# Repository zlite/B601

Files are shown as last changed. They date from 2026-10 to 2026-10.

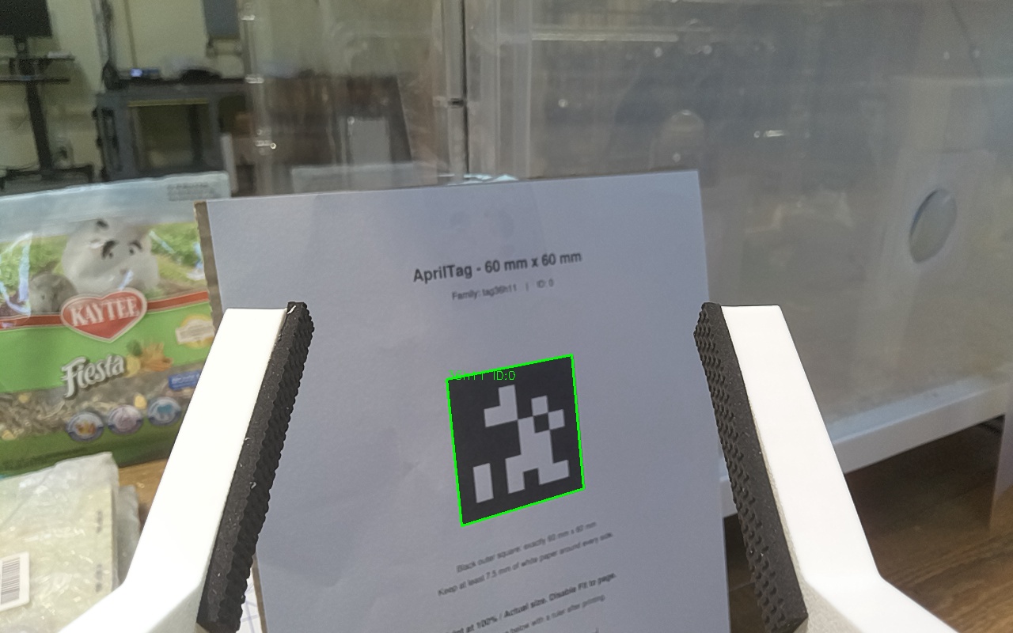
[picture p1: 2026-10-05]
calibration/handeye_20261001T234501896017Z_007.jpg

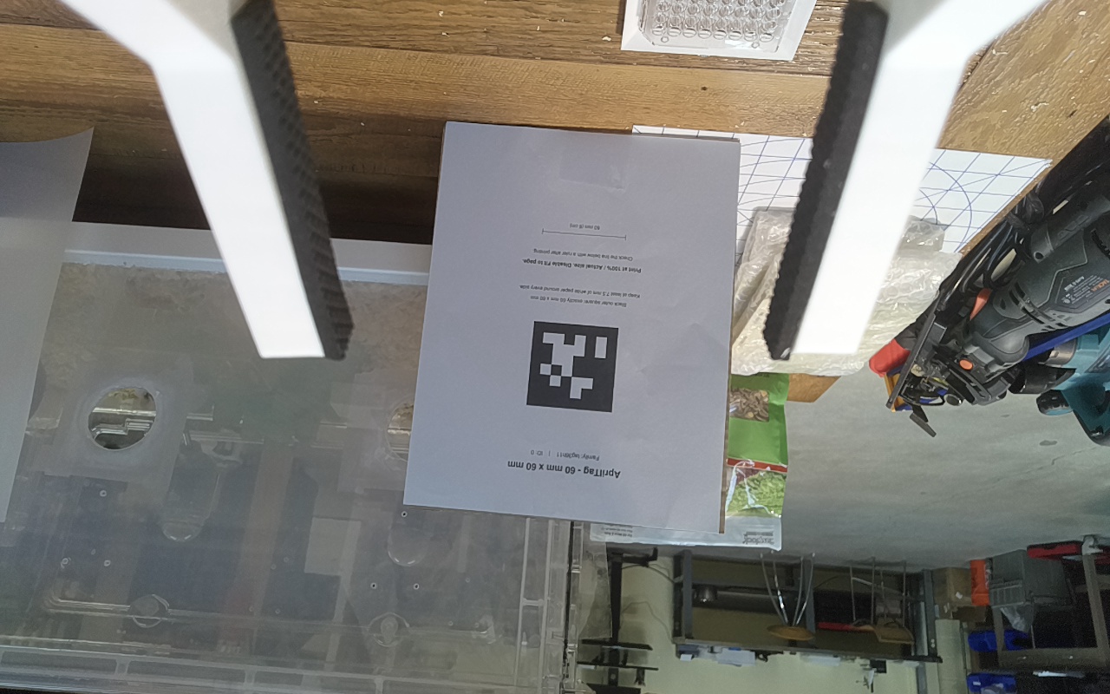
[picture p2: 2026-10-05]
calibration/handeye_20261001T234501896017Z_014_raw.jpg

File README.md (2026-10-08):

# B601-DM + OAK-1 hello-world

A gentle wrist wave while reading RGB images from the wrist-mounted Luxonis OAK-1.
Uses Seeed's motorbridge driver and Luxonis DepthAI v3. No recalibration or zero-position writes.

## Current printer teaching and rail demo (October 7, 2026)

October 8 camera-guided targeting commissioning supersedes the replay below.
The fixed demo is disabled. `printer_plate_vision.py` independently acquires
the complete 12×8 well lattice in the OAK stereo pair, validates 9 mm spacing,
rigid fit and reprojection, and rejects incomplete/ambiguous observations.
It reports a symmetric plate pose, **not A1 well identity**. A separate process
keeps grid detection off the live camera and motor threads. No historical
well-grid bootstrap or saved bed-to-plate offset is used.

`printer_target_plan.py` requires stationary joint readback bracketing the
exposure, the bed tag in that same stereo pair, a fresh stopped rail, and
current arm calibration. It composes bed-attached obstacles with the observed
bed pose, plate obstacles with the independently observed plate, and leaves
printer frame/gantry/syringe obstacles fixed. It solves a fresh local side
approach stopping 65 mm above the plate; it does not translate the old replay.
The planner inflates external obstacles for registered uncertainty and joint
tracking bounds. Its output is a **preview**, not an executable authorization:
full self-collision checks, validated geometry and a physical rehearsal remain
necessary. It cannot automatically move from rest to an unseen target.

The web panel shows localization failures and offers raw stereo capture and
preview without any motor commands. Preview requires three independent stable
observations and is invalidated by target movement, stale data, a camera restart
or rail movement. `config/printer_target_scene.json` deliberately leaves the
unmeasured scene/tool registration incomplete. Automatic target-relative
execution and plate pickup are **not commissioned or implemented in the demo
executor**. Live acquisition at a clear observation pose, scene/tool calibration,
an independently checked acquisition corridor and execution integration are the
remaining work; software tests are not physical validation.

Read-only tools:

```bash
.venv/bin/python scripts/printer_target_client.py status
.venv/bin/python scripts/printer_target_client.py capture
.venv/bin/python scripts/printer_target_client.py preview
.venv/bin/python scripts/analyze_printer_grid.py <target_captures/stage_01>
.venv/bin/python scripts/printer_stereo_viewer.py <teaching-session/target_captures>
.venv/bin/python scripts/dashboard_read.py --brief --axes
```

The standalone stereo viewer serves upright **snapshots**, with visible image
age, at `http://127.0.0.1:8766`. Its only action requests a raw image capture
from the existing camera owner; it has no arm or rail controls and needs no
controller restart. Use it to check both measuring-camera views: the RGB
preview can look clear while a finger obscures the tag or plate in one eye.

October 8 contact incident supersedes the close-approach validation below:
the operator confirmed that the arm knocked the plate out. Recorded wrist
frames show the plate being dragged and tilted during the return of cycle 6;
cycle 7 later paused on roll settling. A completed motor trajectory report is
not evidence of collision-free operation. The old plate-level route is retired.
The replacement `standoff_recovery_20261008T2024` retains only the first two
approach groups, omitting the final three descent groups and `plate_view`.
Its tool bottom is approximately 82 mm higher in the model; this is a relative
pose difference, not a calibrated measurement of clearance from the scene.
All 1,150 stock/tool/camera geometry samples passed, with camera review of
external structures and 16 focused tests. One bounded rail/standoff/return trial
completed in 104.16 s of arm motion, with no visible plate displacement in
reviewed camera views and motors disabled at rest. Repeating standoff demo
then restarted. This does not validate the retired plate-level route.
The original plate-contact cause and scene-relative pickup targeting still
need investigation; this shortened demo does not attempt pickup.
Evidence: `outputs/printer_replay/contact_incident_20261008/diagnosis.json`.

October 8 process-exit recovery: the 17:38 UTC controller recorded 42 completed
cycles before its recording ended abruptly at 19:27:49 UTC, with no final report
for the interrupted return. All six motors subsequently reported communication
watchdog faults. The process termination cause is unresolved. After operator
confirmation of supported rest, faults were cleared without enabling motors.
The final folded rest (joint 3 about 99.50 degrees) passes the unchanged rail
parking interlock; a fresh entry and reverse passed stock-arm, tool and camera
mesh checks in `outputs/printer_replay/folded_recovery_rest_20261008T2000`.
The 20:01 UTC controller also saves console output to
`outputs/printer_teach/controller_20261008T2000.log` for diagnosis.

October 8 roll-load correction (two complete live trials passed): increasing endpoint
wait time alone did not resolve a persistent .95-degree roll offset. Roll's MIT
controller used Kp=18, Kd=2 and no feedforward; observed stationary torque was
about .32 Nm. Demo-only command gains are now Kp=30, Kd=2.6, set only while all
motors are disabled. The damping increase approximately follows the square root
of the stiffness ratio. Teaching restores Kp=18, Kd=2 after a disabled demo end.
No motor mode, EEPROM, zero, commanded path, tracking cutoff or endpoint
tolerance changes. Both trials returned to rest and disabled normally, without
pauses or faults; the repeating run then began its next rail cycle. The loaded
endpoint roll errors were .543 and .544 degrees (unchanged .75-degree tolerance),
and maximum tracking errors were 1.019 and 1.022 degrees (unchanged 1.5-degree
fault limit). Arm cycles took 125.15 and 125.08 seconds. Peak observed motor
temperature was 36 C. These are two-cycle results, not long-duration validation.
Summaries: `outputs/printer_replay/ui_demo/20261008T171425593243Z/summary.json`
and `outputs/printer_replay/ui_demo/20261008T171938199644Z/summary.json`.
The main suite ran 370 cases with four optional CAD skips.

October 8 endpoint follow-up: the first updated cycle completed, but cycle 2
paused at `settling_timeout`. Roll was still about .77 degrees from its target
at the four-second deadline, and subsequently converged inside the unchanged
.75-degree endpoint tolerance. Endpoint holding now permits up to eight seconds,
exits as soon as all original tolerances pass, and reports the limiting joint
and measured error if it times out. Camera/attendance readiness is checked
during settling as well. Recorded-convergence and nonconvergence regressions
passed. A subsequent eight-second live trial still paused with .955-degree
roll error and was returned along its checked route with motors disabled.

October 8 roll-pacing correction: the next sequential-reader run stalled near
the plate while joint 6 retained almost exactly one degree of command error.
The trajectory clock and command cap both stopped advancing at that error.
Replay now permits 1.25 degrees of command error on roll only, while the other
five axes retain their one-degree pacing margin. The independent measured
tracking stop remains 1.5 degrees; gains, path geometry, joint limits and speed
limits are unchanged. Near the pacing cap, less than .02 degrees of commanded
progress over five seconds causes an explicit joint-specific held pause.
Tests exercise the recorded starting error with simulated breakaway in both
directions, a nonfollowing joint, and the independent tracking stop. The main
suite passed 364 tests (four CAD skips); those four passed in `.venv-cad`.
Physical recovery and the combined gain/pacing update passed the trials above.

October 8 communication recovery supersedes the fast-reader results below:
the concurrent reader is now experimental and off by default. The teaching
controller uses the original sequential reader while retaining the smoothed
route and existing speed/acceleration bounds. An observed long-hold deadline
failure is recorded in the local trial `20261008T160050434745Z`; all six motors
subsequently reported LOST_COMM. Powered-fault report writing and CAD-worker
shutdown now wait until the motor owner's cleanup attempt and handle closure
finish. The original control fault is retained alongside any cleanup error,
and power state becomes unknown until fresh verification instead of retaining
a stale `powered: true`. Tests inject the deadline and a second cleanup failure
and verify that no report writing occurs before motor cleanup.
The operator confirmed supported rest before the six communication faults were
cleared and disabled status was verified. The configured entry was checked again
from that actual rest in `outputs/printer_replay/recovered_rest_20261008/`.
The ~129 s sequential-reader cycle is the previous measured reference; the
combined live trials above use the sequential reader.

October 8 power-up recovery: the old worker retained a position-read timeout
fault after motor power returned. Position transactions now get one bounded
fresh retry, like status reads; the 120 ms batch deadline and fault guards stay
unchanged. A disabled starting pose outside the teaching envelope keeps live
readback running and blocks teaching instead of killing the connection.
The operator confirmed normal supported rest, differing from the prior start by
up to 2.71 degrees. A new entry and its reverse passed the existing stock-arm,
gripper and camera mesh checks, preserving the unchanged route tail, in
`outputs/printer_replay/powerup_rest_20261008/`. The Demo config uses that entry;
joint limits and live start tolerances were not widened. Demo readiness was
verified with motors disabled; a motion trial from this new entry is pending.
72 focused tests passed. Refresh the browser after a controller restart to
obtain its new action token before using Demo.

Run `.venv/bin/python printer_teach.py` and open `http://127.0.0.1:8765`.
The controller starts with the arm disabled. The page supports relative leader
teaching, held-arrow rail jogging, and the confirmed same-scene Demo: rail
300 mm left and back, then open-jaw plate approach and return, repeating until
Stop. Pause holds immediately; Stop completes the current cycle at rest.
The demo does not grasp or lift the plate. Fresh resting-pose, scene and rail-sweep
confirmations are required each start. Changed bed positions require new targeting.

Historical fast-reader trial (superseded by the sequential-reader correction
above): the bounded trial returned to rest with motors disabled and rail X=0.
Three smoothed motion sections replace seven
stopped chunks, with maximum checked joint-path deviation 0.071 degrees.
Fresh concurrent motor reads reduced the measured full arm cycle from 129.24 s
to **114.14 s** (11.7% less time). Median control-loop interval fell from
50.86 ms to 11.68 ms; the new 95th percentile was 16.60 ms and maximum 88.57 ms.
Peak tracking error was 0.981 degrees against the unchanged 1.5-degree fault
limit. Motor gains, speed limits and acceleration limits were unchanged in this
comparison. Rail-return-to-arm-motion measured 2.07 s, including the fresh
entry geometry check. This is one measured cycle, not a long-duration reliability
claim. Its summary is versioned at
`outputs/printer_replay/ui_demo/20261008T011256235081Z/summary.json`.

The optional pinned native reader, build command, freshness behavior and
read-only benchmark are documented in [native/motorbridge/README.md](native/motorbridge/README.md).
Without that build, the controller uses the original sequential reader.
The exact reviewed route and collision inputs/results under
`outputs/printer_replay/smooth_demo_v1/` are explicitly versioned so the trajectory
is preserved. Bulk session logs, camera recordings and compiled binaries remain
local. Geometry files retain their source hashes, including workstation paths:
a different checkout location or changed geometry needs fresh evidence rather
than edited hashes. The existing pinned vendor geometry and isolated CAD
environment are still required for the demo entry checker.

For an attended single-cycle test, use
`.venv/bin/python scripts/printer_demo_client.py start --once` after verifying
the same scene and clear movement area. It maintains the attendance heartbeat
and requests stop at the end of the first cycle. No client automatically resumes
a paused trial. The sections below preserve chronological development history;
older pending-state descriptions are superseded by this current status and
`config/printer_resume_state.json`.

## Relocated workspace and Arducam overview (October 6, 2026)

The operator confirmed that only the arm location and tripod camera changed;
the wrist camera, fingers and their mounts stayed unchanged. Existing plate,
holder and table references remain historical. The relocation marker remains
active, and both plate-hover and the standalone old survey route check it before
opening hardware. No new motion path has been validated.

The tripod is now an Arducam Global Shutter 2.3MP with a replacement fisheye lens,
serial `Arducam_20260506_0001`. `config/cameras.json` selects its stable V4L2 path,
MJPEG at **1920×1080, 30 fps**. USB 3 is required: the initial USB 2 hub connection
advertised only 640×480 at 10 fps. Moving it to a 5 Gbps connection exposed the
full modes. The configured USB 3 path/serial deliberately fails closed on a
different device or USB 2 fallback; the backend does not silently resize frames.
Manufacturer mode table:
https://www.arducam.com/arducam-2-3mp-color-global-shutter-usb3-uvc-camera-module-with-onboard-isp-for-robotics-and-machine-vision.html

`uvc_camera.py` supplies an overview image with its native aspect ratio and
advancing driver timestamps. It provides no camera matrix, distortion parameters
or metric pose; OAK-1 calibration must never be applied to these fisheye pixels.
V4L2 driver-buffer age is not independently measured exposure-to-display latency.
The timestamp comes from OpenCV's V4L2 `CAP_PROP_POS_MSEC` implementation:
https://github.com/opencv/opencv/blob/4.12.0/modules/videoio/src/cap_v4l.cpp

Start the read-only camera/arm dashboard with `.venv/bin/python pairing_dashboard.py`
and open `http://127.0.0.1:8765`. It has no motor activation/movement endpoint.
Stop it before any other device client. For a new stationary image record, run
`.venv/bin/python scripts/workspace_capture.py`; this camera-only tool creates a
unique folder under `outputs/workspace_revalidation` and never clears the motion
block. Fresh tripod frames are retained at native 1080p; wrist images retain their
existing calibrated sensor coordinates and separate upright previews.

The first successful dual-camera record is
`outputs/workspace_revalidation/20261006T183131149101Z/report.json`: 55 sampled
tripod frames and 20 wrist frames, median driver/SDK frame ages 16.3 ms and
101.0 ms respectively. Neither reference tag decoded at the resting pose.
`outputs/contact_camera/20261006T182403188657Z/report.json` separately preserves
12 stationary wrist RGB/stereo triplets; none established a tag pose.
Read-only inspection found all six arm drives and the gripper disabled, with
gripper position −1.15238 rad. The existing Python environment's broken symlink
into `/tmp` was repaired to point to its already installed local interpreter.

The operator subsequently confirmed that the target or task has changed. The
new object, interaction and destination are pending; do not assume the old plate
pickup task or reacquire its geometry as the new task. Define the new task before
planning its workspace measurements or empty-jaw rehearsal. The new view includes
nearby gantry structure; old clearances and trajectories are not evidence for this
workspace. Fifteen focused camera, pairing and relocation-gate tests passed.

The new target was then identified as a 96-well plate on a 3D printer bed, with
AprilTag **36h11 ID 18** in front. `config/printer_bed_target.json` records the new
identity separately from the historical tag-0/contact configuration. The tag's
physical black-square size and requested plate operation are awaiting confirmation.
Current wrist RGB and both mono cameras decoded ID 18 in all 12 triplets saved in
`outputs/contact_camera/20261006T183713670011Z/report.json`. Independent stereo
triangulation, without a tag-size assumption, puts its center approximately
200 mm from camera B and its four side lengths at 17.9–18.4 mm. This is an
observation, not a substitute for physical size confirmation or a bed/plate pose.
The center's stationary coordinate standard deviations were 0.023, 0.056 and
0.110 mm; maximum stereo reprojection error was 0.711 px. Details are in that
folder's `tag18_stereo_observation.json`.

Fresh native-resolution RGB/overview evidence is in
`outputs/workspace_revalidation/20261006T183755006277Z/report.json`. The dashboard
now annotates visible tags even when they are not the old metric reference.
Discovery with `contact_camera_probe_v2.py --all-tags` no longer assigns the old
60 mm size to an unknown tag. A metric capture requires an explicit paired
`--tag-id` and `--tag-size` in metres (or the original default tag definition).
Twelve focused probe, stereo geometry and pairing tests passed. Arm and gripper
readback remained disabled; no motion was commanded and the relocation block
remains in place. The printer's bed and gantry introduce geometry absent from
the old tabletop routes.

The operator confirmed ID 18's black square is **18 mm** and requested a lift
and replacement at the same position, with a collision-aware side approach.
The 12 stereo-only tag fits pass their size, reprojection and rigid-square
checks, but RGB/stereo comparison fails: the 640×360 RGB tag pose differs by
about 21 mm. The later 1280×800 RGB observation also differs from stereo in
range. Do not treat the combined metric check as passed or use this discrepancy
as permission to relax thresholds. Lower-exposure stereo evidence is saved in
`outputs/contact_camera/20261006T184603745832Z`.

`printer_approach.py` is a new **offline-only** plate-frame IK candidate generator.
It does not open hardware and has no execute option. It generates retreat/rise,
alignment outside the fixture, side-entry and a 40 mm noncontact standoff,
plus the reverse sequence. Parallel-jaw orientation symmetry avoids a spurious
180-degree wrist flip when the newly seeded grid axes differ from the old grid.
The current candidate has 248 waypoints, maximum adjacent joint step 0.759°,
and large overall changes (approximately 37° base and 41° shoulder), so fingertip
clearance alone is insufficient. Candidate and manual 96-well image registration
are under `outputs/workspace_revalidation/20261006T183755006277Z/`.

The seven missing stock-arm collision meshes were retrieved from the same pinned
Seeed commit as the URDF. Their hashes/bounding boxes are recorded in the candidate.
A 1,344-sample stock-link box check clears a **provisional plate volume only**
with 15 mm obstacle inflation; this is not complete scene or tool validation.
Printer bed, fixture, adjacent container, gantry and installed tool/cable volumes
still require registration/verification. The corrected operator-supplied deck is
retained at `cad/printer_bed/LH_deck_four_bolt.stl`, with provenance, hash, dimensions
and correspondence evidence in `LH_deck_four_bolt.inspection.json` beside it.
Its plate recess, adjacent square support and mounting pattern match the scene.
The mesh bounds are 202.58 × 186 × 14.2 native units; millimetres are provisionally
supported by a 170 mm CAD mounting-hole spacing versus approximately 171.95 mm
between manually marked stereo bolt-head centres. The plate opening at CAD
z=6.2 mm is 128.36 × 86.08 mm; the raised rim reaches z=14.2 mm.

A three-feature stereo registration candidate has maximum stereo reprojection
error 0.17 px and maximum rigid-fit residual 1.60 mm. These residuals do not
validate the registration: bolt-head height is assumed, one oblong-slot centre
is manually approximated, and elevated rim landmarks still need independent
verification. The tall container and printer gantry are not included in the STL.
Six-view inspection of the earlier, superseded bracket export is preserved as
historical evidence; it is not the configured deck. Corrected deck views and a
provisional stock-arm/deck bounding-box diagnostic are in `outputs/holder_cad/`.
`config/printer_bed_target.json`
records these unresolved items and stays `motion_ready: false`; the old relocation
marker remains. Twenty-two focused tests pass. No motors have been enabled and
no physical rehearsal, grasp, lift or replacement has been attempted in this setup.

The operator measured the plate top **10 mm above the holder rim**, confirmed
there is no removable lid, and said the printer bed stays still during the pickup.
The bed may occupy a different Y position between attempts. Every attempt must
therefore reacquire a fresh wrist stereo reference and check plate seating; an
old saved bed position is never an executable target. Bed-attached geometry must
move with the observed bed; the fixed printer gantry must not.

The October 6 19:20 UTC capture in
`outputs/contact_camera/20261006T192021891418Z/` has 11 valid stereo tag fits.
The tag moved 52.98 mm relative to the wrist while subsequent arm readback was
essentially unchanged. All earlier printer approach candidates are consequently
historical and explicitly invalid for the current scene. The operator's 10 mm
height plus the preliminary CAD registration also disagrees with the old RGB
plate seed by 8.73 mm in centre position; the tag-to-plate transform is not yet
validated.

The offline approach solver now aligns the **measured** contact-pad direction
instead of the nominal 45-degree bend. `printer_grasp_clearance.py` adds sampled
pad-volume checks and a full-face contact-height diagnostic. The earlier
8 × 61 mm pad calculation is superseded: the operator confirmed **both installed
pads are 60 mm long, 10 mm high and 3 mm thick, flush with the printed finger
ends**. A 10 mm pad has zero full-face height tolerance in a nominal 10 mm band;
one degree of pitch adds approximately 1.05 mm to its vertical extent. A pad
projecting above the plate may permit partial-face contact, but its contact area,
grip and rim clearance still require validation. Historical pad-only trajectory
checks do not validate the new geometry or the displaced bed.

The supplied `cad/grippers/B601_clean_braced45_assembly.step` has explicit mm
units. `cad/grippers/inspect_step.py` extracts the two rigid fingers into 28
conservative section boxes; `gripper_cad.py` adds two measured pad boxes from
`cad/grippers/installed_pads.json`, replacing the STEP's 61 × 8 × 1 mm pads.
The reference plate in the STEP is excluded from the robot collision model.
At the same rigid-body opening the extra rubber reduces the gap by 4 mm relative
to the CAD pads. This is not a measurement of the current open gap.

Distal pad ends are placed at CAD X = −32.5 mm; vertical centering on the plastic
face is still a hypothesis. Stereo landmark registration is also provisional.
The candidate in `outputs/gripper_cad/installed_pad_registration_candidate.json`
brackets center/upper-seam landmark hypotheses; this is not a certified error
bound. It excludes the gripper housing, camera mounts, cables and self-collision.
The earlier nominal-pad and tool/deck reports are marked superseded. No motion
is enabled by importing CAD or passing an offline box check.

`pairing_dashboard.py --printer-target` selects a read-only stereo tracking mode.
`printer_target_tracker.py` rejects stale/lost/restarted/displaced references and
permits a base-frame tag estimate only with fresh stationary joint history. It
cannot yet localize the plate or authorize motion. The stereo mode uses a separate
DepthAI 2.32 camera subprocess because the DepthAI 3 generic three-camera pipeline
crashed during sensor startup. The normal RGB-only dashboard mode is unchanged.
Inspect the current observation with
`.venv/bin/python scripts/dashboard_read.py --brief --target`.

The small-tag retry (`detect_small`) recovered the missed detection in all 12
saved stereo pairs without relaxing the metric checks. The live 15-second check
at `outputs/printer_tracking/20261006T193318873835Z.json` observed 75/75 valid
samples, with maximum observation age 149 ms. This validates detection/freshness,
not grasp precision: the small tag's raw orientation varies enough to trigger
conservative reference invalidations even during this stationary check. The
focused geometry, tracking, capture and relocation-gate tests pass. No arm or
rail motion has been commanded. The operator confirmed the gantry/toolhead
also stays stationary during trials and supplied the finger CAD described above.

The operator also identified a later phase: the arm base rides on a stepper-driven
rail controlled by a computer-connected GRBL/Arduino board, with an X+ limit
switch. Rail homing and positioning are deferred until stationary plate pickup
is reliable. No rail commands have been sent. Controller settings, limit polarity,
homing direction, travel limits and the rail-axis/base transform must be measured
before coordinated rail/arm motion. Rail position must update all workspace
transforms and collision checks; existing references apply only to the current
stationary rail position. This deferred work is recorded in the target config.

### Continuing from the operator-selected pose, October 6

The operator repositioned the arm and relocated tag 18. Earlier base-frame
targets and paths remain invalid. `scripts/printer_stationary_capture.py` now
brackets every camera exposure with read-only arm/gripper telemetry and rejects
captures with arm/jaw movement, missing time coverage or long readback gaps.
The accepted capture is `outputs/contact_camera/20261006T205427296547Z/`.
Its joint report verifies a stationary arm and gripper at −1.15243 rad.
The camera probe records exposure timestamps on the host monotonic clock and
can fit B/C stereo independently of RGB visibility. It never commands motors.

At the new viewing angle 2000 us overexposed tag detail in the mono cameras.
1000 us, ISO 100 recovered 10/12 offline stereo fits; live tracking then gave
50/50 valid samples in `outputs/printer_tracking/20261006T205755527700Z.json`.
The dashboard uses that exposure. Small-tag orientation remains noisy, and
successful detection does not establish a validated tag-to-plate transform.

The elbow starts within its nominal model range but inside the extra 0.005 rad
planning margin. The offline solver admits this measured start only with
inward recovery: bounds tighten as the joint recovers and cannot reopen.
No nominal joint limits are widened. A 1.2 rad offline search radius finds a
continuous candidate; the former 0.8 rad local search bound was too narrow.
The return candidate ends at the raised outside-fixture pose, avoiding a return
to the near-limit starting pose. This is an offline IK change, not permission
to energize motors or evidence of calibrated motion accuracy.

The retained offline candidate is
`outputs/contact_camera/20261006T205427296547Z/side_approach_current_pose_standoff65_candidate.json`.
It ends at a 65 mm noncontact standoff above the provisional plate plane.
The more aggressive 40 mm descent intersected an oversized container hypothesis
and is not the selected candidate. Visible stereo points place the container
top near 45 mm above the provisional CAD datum; the revised diagnostic uses a
55 mm-high, 62 × 62 mm envelope, plus the existing 15 mm obstacle inflation.
That local finger/container check passes with a 9.2 mm separating-axis gap
beyond inflation. The provisional deck check also passes. Neither check covers
the entire scene: holder registration, installed tool details, self-collision,
the gantry/toolhead, surrounding structures and rail still require validation.
The plot `current_pose_trajectory_review.png` shows the substantial arm sweep.
No motion has been commanded, and the relocation marker remains set.

The stock Ender 3 assembly is retained at `cad/ender3/Ender3.STEP`, from
Creality commit `88c7758cea9d0d00a54fdb238bedb3b33425f409`. Its 311 located
components and selected structural bounds are in `inspection.json` and
`structural_reference.json`. These are unregistered reference geometry:
the bed travel and gantry height in the STEP are not the current machine's
positions, and the custom syringe drive, needle and rail are absent.
`inspect_step.py` preserves repeated instances and resolves their product names.

A small offline wrist-bend observation candidate was also checked using stock
triangle meshes. The saved folded starting pose has a modeled link2/link5
surface intersection; link2/link4 separation during that candidate is only
about 0.6 mm. This does not establish physical contact, but prevents declaring
the move clear. The camera cannot resolve that narrow gap. The operator was
asked whether there is visible physical clearance, without moving the arm.
`scripts/stock_mesh_self_check.py` provides a reproducible FCL diagnostic of
precomputed collision-mesh transforms. It excludes adjacent engineered joints,
checks all other pairs, and never authorizes motion. It checks triangle surfaces,
not solid containment, and does not cover the custom tool or external obstacles.

The full 65 mm-standoff candidate was subsequently **rejected** by the stock
self-check: 295 of 1,577 interpolated samples have less than 5 mm separation,
and 236 samples report link2/link5 surface intersection, all during the initial
`retreat_and_raise` stage. See `side_approach_stock_self_check.json` in the
accepted-capture directory. The earlier fixture clearance result does not make
this trajectory usable. A different initial unfolding motion is required.

Fresh readback at 21:26 UTC differs from the saved capture by about 1.17 degrees
at joint 1 and 0.42 degrees at joint 4. The ten-second sample was stationary,
but only 8/50 tag observations were valid (tag clipped in the wrist view).
Historical tracking success and saved paths must not be treated as current
validation. See `outputs/printer_tracking/20261006T212600370966Z.json`.

From that fresh readback, an offline alternative first reduces raw joint 3 by
2 degrees, then raw joint 4 by 8 degrees. This raises the modeled fingertips
about 61 mm. Its 101 stock-mesh samples show no surface intersections, but the
first 15 samples remain inside the 5 mm diagnostic margin while unfolding.
This is a promising observation candidate, **not a cleared movement**: physical
starting clearance, complete tool geometry and external swept clearance remain
unverified. Reports are `local_observation_mesh_input.json` and
`local_observation_stock_self_check.json` in the accepted-capture directory.

### Return to normal rest, October 6 at 21:36 UTC

The operator confirmed that the wrist housing physically touched the long beam
in the previous pose, then manually returned the arm to normal rest. The new
stationary, disabled-arm/gripper capture is
`outputs/contact_camera/20261006T213644834808Z/`. Tag 18 is outside the wrist
view (0/12 detections), which is expected at rest and is not itself a reason to
reuse an old target pose or approach.

An offline search candidate unfolds the elbow 30 degrees, turns the base about
72 degrees, then aims the wrist camera toward the historical target bearing.
`rest_search_mesh_input.json` and `rest_search_self_check.json` record 1,703
stock-mesh samples with no surface intersections. The first 16 samples retain
less than 5 mm separation as the folded arm begins opening. A coarser 171-pose
finger/pad check reports no sub-5-mm proximity to stock links 0–5. This does not
validate the camera housing, gripper motor, cables or external scene. It is
not an execution plan, and the tag must be reacquired before plate targeting.
Several wrist-steering alternatives were rejected because of modeled
self-intersection or insufficient clearance.

The operator adjusted the ArduCam twice; the rear elbow and adjacent bench
are now visible. Earlier front views are retained. This camera remains an
uncalibrated overview; no metric clearance is inferred from its fisheye pixels.

The first physical observation trial, `20261006T215822174941Z` under
`outputs/printer_observation_lift/`, lifted the elbow eight degrees at a
1 degree/s cap, then returned along the same segment. All six drives held
position; gripper and rail were untouched. Maximum elbow tracking error was
0.259 degrees, and motor shutdown was independently verified. The wrist bend
settled about 0.66 degrees after shutdown, so subsequent plans use fresh joints.
This validates one bounded lifting segment, not a plate approach or pickup.

The updated offline viewing route unfolds the elbow 20 degrees, raises the
shoulder 12 degrees, then turns and aims the camera in separate small steps.
Its settled-start evidence is in `outputs/printer_observation_route/settled_20261006/`.
The stock gripper base is included as a fixed part of link6. A conservative
camera enclosure bound and the supplied finger/pad hypotheses were checked
separately. Printer registration, mount/cable envelopes, and grasp registration
remain incomplete. `printer_observation_route.py` defaults to preview; execution
requires fresh images to be reviewed at each stopped waypoint. Missing review
or a camera freshness failure triggers retrace; motor faults use torque-off
cleanup. This observation controller does not clear the workspace pickup block.

Staged run `20261006T221343056382Z` completed seven waypoints: elbow opening
20 degrees, shoulder lift 12 degrees, and base rotation to 20 degrees. Images
were reviewed between segments. At the last stop the raised rear elbow reached
the lower overview-image boundary, so further rotation was canceled. Controlled
retrace to rest and disabled drives were verified. Maximum tracking error was
0.264 degrees. No grasp, gripper or rail command occurred, and the target tag
was not reacquired. The operator was asked to move the ArduCam farther away and
higher to cover the complete turning area. The arm settled again after power-off;
the saved route must be regenerated from fresh joints before another execution.
Evidence and images: `outputs/printer_observation_route/settled_20261006/20261006T221343056382Z/`.

The operator cannot move the ArduCam farther back or higher; its placement is now
fixed. The compact observation run at
`outputs/printer_observation_route/compact_fixed_camera/20261006T222626191083Z/`
completed 16 stops but aborted during the final wrist bend: roll drifted 0.571°
from its fixed target, beyond the 0.55° envelope. This caused torque-off cleanup,
not controlled retrace. The arm settled under gravity; a separate read-only
inspection confirmed all six drives disabled. Hold compliance is a possible
cause, not a completed diagnosis. The user manually returned to rest, then
rotated the follower to align with the newly connected leader. Old route starts
are invalid. No pickup or rail operation was performed.

`printer_teach.py` provides an attended approach demonstration panel at port
8765, starting with all motors disabled. It reuses the existing relative,
hold-to-follow controller with the existing 18°/s, 60°/s² first-three-axis profile
and 24°/s, 80°/s² wrist profile. Model/local travel limits and motor guards remain
active. Teaching captures the leader reference on the first press and preserves
it through startup, limit saturation and ordinary pauses. A resumed press requires
the leader's mapped request to match the held follower within 1°; the explicit
Re-align button accepts the current pair of poses during powered pause without
moving the follower. It never matches old absolute encoder origins. Release
pauses with motor power on. Motor
power removal requires physical support; faults may still remove torque.
The first pass stops before plate contact; gripper control remains inactive.
The printer stereo runtime and current ArduCam feed are used without moving the
overview camera. The revised panel/controller passed 76 combined rail, teaching,
axis-following, wrist-following and observation tests; the live page was visually
checked. Teaching uses 20 ms smoothing with braking at the requested target to
avoid command overshoot, and a 5 ms leader polling pause instead of 20 ms.
Other clients retain their existing mapping and trajectory policy. Motor
feedback polling, gains, speed limits and fault checks remain unchanged.

The October 7 demonstration showed additional alignment shifts at startup and
re-press (about 3.1° on joint 4), rather than within the second uninterrupted hold.
Joint 3 also repeatedly reached its folded-end model limit after startup/re-press
discarded leader movement. The latest reference policy removes those silent
changes; it does not expand joint ranges. Dynamic motor tracking lag reached
about 6° during the earlier trial and still needs a measured physical retest.
No physical gain/scale correction was inferred solely from these encoder logs.

The October 7 session `20261007T231900689788Z` isolated the reported joint-2
descent problem to the shoulder's local 60° teaching window. The leader requested
128.4° while both the command and measured follower stopped at a 60° excursion.
`teaching_profiles()` now allows the shoulder's full model-defined range by
using a 180° local window intersected with the existing calibrated URDF bounds
and endpoint margin. Shoulder speed remains 18°/s and acceleration 60°/s²;
tracking checks, other joints' ranges and hardware limits are unchanged.
55 teaching/axis/rail tests passed, including the recorded 128.4° request,
trajectory limits and saturation at the model endpoint without reference drift.
After a supported motor-off restart, the operator confirmed the shoulder fix
worked and recorded the successful approach in `20261007T232631093383Z`.
Diagnosis: `outputs/printer_teach/20261007T231900689788Z/joint2_limit_diagnosis.json`.

`printer_demo_replay.py` subsequently completed a staged open-gripper approach
and autonomous return using the cleaner demonstrated withdrawal in reverse.
The operator confirmed the rail, bed, plate/holder and syringe/gantry had not
moved. The checked route uses 3°/s motion with fresh wrist/overview images,
stationary-rail checks, tracking limits and camera review at each stopped stage.
It reverses the identical executed curves for withdrawal, avoiding a dense
telemetry refit that made an earlier return impractically slow. An earlier
0.5° wrist pacing stall was also corrected; interrupted pacing holds for review.
31 relevant tests passed. The successful run is
`outputs/printer_replay/20261007_demo/corrected_return_route/20261008T000046228761Z/`.
All four approach stages and the return completed; all arm motors were verified
disabled. Peak recorded joint error was 0.963°, and return motion took 158.5 s.
Modeled wrist travel fell from 2.083 m to 1.058 m (49%); summed joint travel fell
38%. These are path/model comparisons, not a claim of a globally shortest path.
The plate was not grasped or lifted. This same-scene trial does not validate
changed bed Y, autonomous rail positioning, metric scene registration or a grasp.
Replays require fresh starting-pose/scene checks; saved angles are not restart
commands. Stock checks include a monotonically opening tight folded start;
finger/camera registrations remain provisional.

The teaching panel now also has an attended **Demo** loop: confirm the resting
pose, unchanged scene and clear sweep, move the rail 300 mm left and back,
execute the open-jaw approach/return, and repeat until stopped. **Pause now**
holds immediately; **Stop after this cycle** finishes at rest. Loss of the
owner heartbeat, camera freshness or rail readiness pauses execution and
requires explicit resumption. Rail idle release remains configured with `$1=0`.

The smoothed route in `outputs/printer_replay/smooth_demo_v1/` joins five middle
curve pieces into one continuous section, leaving three stopped sections instead
of seven. The maximum change from the prior checked curves is 0.071° per joint;
1,428 stock/tool/camera samples were checked. Local timing caps joint velocity
at 12°/s and acceleration below the existing 60/80°/s² limits, while feedback
pacing keeps the 1.5° tracking fault limit. The first complete smoothed arm cycle
took 130.0 s versus 162.9 s with the prior 4× profile; actual speed depends on
servo tracking. This remains an open-jaw demonstration, without grasp or lift.

Fixed-route validation, mesh loading and motor configuration happen before the
rail moves and are reused across cycles. After rail return, the controller reads
the actual disabled arm pose and checks a refreshed entry from that pose using
the same mesh geometry and margins (about 1.5 s offline). It verifies that pose
again before enable. Passive wrist shifts during rail travel do not invalidate
the demo; the folded-arm rail interlock remains active. The completed return
ends at the original checked home pose, preventing accumulating wrist offset.
The updated live cycle measured 2.24 s from rail return to arm motion and
129.24 s for the arm approach/return; cycle two started automatically. Evidence:
`outputs/printer_replay/ui_demo/20261008T004919406737Z/summary.json`.
There are no fixed handoff/intercycle delays or demo duration cutoff. Hardware,
scene, freshness, tracking and explicit-stop interlocks still apply. Changed
bed Y and autonomous pickup remain outside this same-scene demo's scope.

Attended rail jogging is now available in the teaching panel. The operator
confirmed unchanged full-step hardware and the limit switch at the right end
of the ArduCam view: Left maps to positive X, away from the switch. `rail_jog.py`
uses the separate physical USB path ending `1.2:1.0-port0`, verifies GRBL 1.1 and
the inspected settings, and streams 2 mm incremental `$J` requests at 1920
mm/min (requested 32 mm/s). It replenishes collinear moves during Jog rather
than waiting for Idle between segments, so GRBL can blend their velocity.
Only one command may await acknowledgement; the total commanded endpoint is
limited to 18 mm ahead of the last reported position, including that command.
The 2 mm segments keep this within nine planner blocks.
At the operator's request, the 25 mm per-hold cap was removed: a held arrow
continues motion while fresh heartbeats and all interlocks remain valid. Only
the outstanding 18 mm buffer is bounded; release cancels it. Tests exercise both
directions for 15 seconds past 400 mm, followed by release. The rail is still
unhomed and only the right end has a verified switch; the operator must stop
before either end or obstacles. The operator confirmed the 8 mm/s trial was
smoother, requested 16 mm/s, then requested another doubling to 32 mm/s.
`scripts/rail_speed_profile.py --apply` sets `$110=1920` and `$120=40` while
Idle, verifying all other settings
unchanged. Doubling acceleration preserves the nominal 0.8 s ramp-up time.
The normal teaching worker only verifies settings. Nominal stopping distance
at 32 mm/s is 12.8 mm before
transport/heartbeat latency and step quantization; this is not measured physical
stopping distance. The hardware still has only 5 steps/mm (0.2 mm per step), so
software blending cannot supply microstepping. The old 1 mm F120 commands
often completed in about 0.2 seconds including host latency. Standard 16 MHz
GRBL with AMASS caps the slowest timer period at 65535 cycles and overdrives
by at most 8, implying about 30.5 steps/s (6.1 mm/s at this scale). That is a
plausible explanation, not an identification of the installed firmware build.
Even the new nominal acceleration/deceleration cannot be assumed physically
accurate at such low pulse density. Microstepping and a new scale check remain
needed. No physical speed or stopping-distance validation has yet occurred.
Key release, loss of focus, heartbeat expiry, stale views or lost arm-rest
interlocks cancel jogging. Cancellation is repeated after acknowledgement to
handle GRBL ignoring a cancel received before entering its Jog state. Both
arm following and rail jogging are mutually interlocked; rail jogging requires
the arm rested with its motor power removed. `$1=0` requests driver disable at
idle; this is a configuration check, not current or enable-pin feedback. The
operator subsequently reported holding current between moves despite recorded
`$1=0` and `$4=0`. Physical driver release is unverified and under investigation;
the UI no longer claims confirmed power-off. Saved hardware is Uno/A4988 with
standard GRBL enable on D8, active low. The October 7 photo identifies a CNC
Shield V3.00; the driver IC is hidden by a heatsink and is not visually confirmed.
The carriage releases when motor supply power is switched off. The operator
measured EN/GND about 0 V even in confirmed Sleep, with 5V/GND about 5 V.
At the operator's explicit request, superseding the earlier no-flash preference,
the rail Uno was flashed with the latest official release, `1.1h.20190825`.
AVRDUDE verified all 29,920 programmed bytes; the prior build reported
`1.1h.20190830`. All 34 settings, coordinate offsets and startup blocks matched
the pre-flash backup, so no settings restore was needed. Firmware, settings,
release metadata and verification logs are in
`outputs/rail/20261007T224432Z_firmware/`. The raw EEPROM read attempt returned
flash bytes from this bootloader and is **not a usable EEPROM backup**; use the
validated textual GRBL backup for settings recovery. Do not write either
EEPROM-named binary back to EEPROM. No motion was commanded. Post-flash enable
voltage and physical driver release were initially unverified after flashing.
The operator subsequently tested the standalone Arduino successfully and replaced
the CNC shield, keeping the same X driver and no microstepping jumpers. Fresh
checks preserved the rail settings and found Idle with clear limit inputs.
Attended arrow-key control resumed in session `20261007T231900689788Z`, and the
operator confirmed the holding-current problem was solved after the trial.
This is operator-confirmed physical release, not electronic current telemetry.
During that investigation, run `printer_teach.py --rail-monitor-only`: rail
jogs are rejected, but fresh Idle/Alarm status permits arm teaching. Loss of
rail status or observed rail motion blocks/pauses arm following. The arm-button
hint reports rail blocking or the unchecked support-and-clearance checkbox.
26 rail/teaching tests passed, including monitor-only alarm, stale status,
unexpected movement and jog rejection. Restart verified arm ready with rail
Idle and no active limit input; holding-current diagnosis remains unresolved.
Limits remain active, and there is no automatic unlock,
homing, settings write in the teaching worker or absolute positioning. The rail remains unhomed;
reported X is only a relative controller coordinate. Startup allows the Arduino
boot banner to finish before identification. Rail events are saved to `rail.jsonl`.
During the operator's first rail trial, the right-end switch produced ALARM:1.
That contact requires physical clearance and a fresh controller/switch check
before jogging resumes. It is not treated as a calibrated home position.

The initial 3°/s demonstration (`20261006T225818356204Z`) was too slow. Its
incremental limit handling also caused joint 4 to retain a -33.3° offset after
leader travel reached +78.5° beyond the local +45° bound. Recorded motor tracking
was within about 1.02° of the commanded joint-4 target, pointing to software
mapping rather than a direction reversal. Offline replay reproduces the old
offset and removes it with the reference-preserving mapping: mean joint-4 command
error relative to the bounded original reference falls from 18.94° to 0.43°.
This is command simulation, not a new physical tracking result. Diagnosis:
`outputs/printer_teach/20261006T225818356204Z/lag_and_alignment_diagnosis.json`.
The corrected session `20261006T230514734367Z` starts disabled and displays live
following error and limit warnings. No motor zero or direction sign was changed.
The operator tested that session and confirmed it worked better, then stopped
for the day. Motor disable and controller shutdown were verified; recordings
are closed. Resume notes are in `config/printer_resume_state.json`, with measured
trial statistics in the session's `operator_trial_summary.json`. After power-up,
inspect fresh device identities, joints and cameras before starting another
relative teaching session. No saved pose is a valid restart command. The full
pickup demonstration, gripper mapping and adaptation to changed bed positions
remain unfinished; the later same-scene open-gripper replay is described above.
Automatic rail homing and task positioning remain deferred; the
manual keyboard jogging added on October 7 is separate.

Teaching records are in `outputs/printer_teach/<session>/`: the control event log,
10 Hz snapshots of source readings and motor state, and approximately 2 Hz JPEGs
from both views with source metadata. These are diagnostic snapshots, not
synchronized metric imagery or an approved replay path. Recording failure or a
30-minute session expiry blocks further following and requests powered pause.
The workspace revalidation block remains in place. Start only after stopping
other arm/camera owners: `.venv/bin/python printer_teach.py`.

`scripts/stock_mesh_self_check.py` uses conservative AABB pruning before FCL
surface checks. Its optional tests run in `.venv-cad` and compare classifications
against analytic cube separations, including both intersections and near gaps.

Existing rail work was found in `/home/chris/grbl-x-axis/calibration.json` and
`resume-state.json`. Those records contain a 5 steps/mm measurement in full-step
mode, an unfinished final homing pull-off/work-zero setup, and a proposed
microstepping change. They label the switch X−, unlike the earlier X+ description.
These are saved records, not a fresh controller inspection; reconcile hardware,
settings and switch direction before rail commands. The operator wants later
rail-position-guided target search: plan a clear arm lift and wrist-camera scan,
acquire the expected tag, then refine the approach. Rail work remains deferred.

## Visual leader pairing workbench (October 2, 2026)

```bash
.venv/bin/python pairing_dashboard.py
```

Open `http://127.0.0.1:8765` on this computer. The page combines live wrist and
workspace RGB views, tag visibility/quality, follower joint readings, a rotatable
B601 joint model, and a cyan preview driven by the FashionStar REbot 102 leader.
It sends **only read queries** to the arms. There is no motor activation or
movement endpoint. Stop the server with Ctrl+C before starting another device
client. `--demo --port 8766` previews the page without accessing hardware.

Match the small leader to the page's Seeed reference photo, confirm its pose,
and click **Save software reference**. After one second of steady readings, the
page saves a session-specific software reference. It does not change servo origins
or the follower reference. The six guided direction checks then record signs from
operator-confirmed visual movements. Each check starts from the current comfortable
pose; returning to the folded reference is unnecessary. Other joints and the
gripper can move freely during a check. Live movement bars show all six joints,
and a focused view freezes the other model joints on screen so the selected hinge
is easier to compare. **Flip it** reverses only that check's preview until the
operator confirms **Looks right · Save direction**. The selected hinge must move
at least 3 degrees (at most 45 in one check) and settle within a 1-degree span
for approximately half a second; other joints do not veto capture. No direction
is inferred from whichever joint happens to move most. Unchecked preview signs come from the
[upstream LeRobot REbot 102 configuration](https://github.com/huggingface/lerobot/blob/main/src/lerobot/teleoperators/rebot_102_leader/config_rebot_102_leader.py)
and remain unverified. Gripper mapping, ranges, scale, motion and collision
validation are not performed. Saved candidates are named
`calibration/leader_pairing_<session>.json` and retain `motion_ready: false`.
References are not automatically loaded on a new run, and leader connection loss
or a large discontinuity invalidates the current reference.

The CH340 leader adapter uses servo IDs 0–6 at 1 Mbaud. Its verified port is
`/dev/serial/by-path/pci-0000:05:00.4-usb-0:3.2:1.0-port0` (currently ttyUSB1).
The rail adapter has the same non-unique
`/dev/serial/by-id/usb-1a86_USB_Serial-if00-port0` name, which was redirected to
ttyUSB0 after reconnection on October 7. Do not use that shared alias for either
controller. All seven leader servo replies were verified on the physical path
before restarting teaching. If the leader is moved to another USB port, identify
and verify its new path before changing the binding. If Linux denies access,
grant the current account access to that verified device, not a guessed ttyUSB
number. Temporary permissions may need repeating after USB reconnection.
`leader_read.py` uses checksummed FashionStar monitor queries with per-query
timeouts, reply-ID checks and no cached-angle fallback. The installed optional
SDK 0.0.4 marks this unit's stationary -0.1° shoulder reading unreliable, so it
is retained only for comparison with `leader_read.py --sdk`; the dashboard uses
fresh monitor transactions. Protocol reference:
[MotorBridge FashionStar protocol](https://github.com/motorbridge/motorbridge-smart-servo/blob/main/smart_servo_vendors/fashionstar/src/protocol.rs).
To recreate that optional SDK: `UV_CACHE_DIR=/tmp/b601-uv-cache uv pip install
--python .venv/bin/python --target vendor/leader_sdk -r requirements-leader.txt`.

The cameras provide visual feedback, not independent link-angle measurements.
The model is not registered as an overlay on either camera. Streams are not
synchronized hand-eye calibration samples. Camera-to-wrist positional validation
and fingertip geometry remain unresolved. The camera startup discards frames
until wrist focus reaches the configured position. Leader pose and direction
captures require an attended operator; the UI cannot establish physical alignment
on its own.

## Run

### Attended wrist-only leader following

After the October 2 ±3° independent wrist wave passed and the operator confirmed
smooth motion, `wrist_follow.py` provides the next bounded experiment:

```bash
.venv/bin/python wrist_follow.py --pairing calibration/leader_pairing_20261002T202428971124Z.json
```

Stop the pairing dashboard first; both applications own the same hardware. Open
`http://127.0.0.1:8765`, confirm support/cable clearance, and **press and hold to
follow**. Startup is read-only. Only the saved, checked wrist direction is reused;
old absolute leader origins are not loaded. Each hold captures fresh relative
baselines. Other leader joints may move freely. Only follower joint6 is enabled;
the other five follower joints must remain supported within 1° of startup.
The first physical following trial revealed opposite wrist rotation with the
preview-derived mapping. The saved pairing now includes a wrist-only raw-to-raw
sign of -1 in `relative_follow_checks`, which overrides that preview mapping for
following. The operator confirmed the corrected physical wrist direction.

Targets remain within ±15° of the **whole session's** starting wrist position,
even across repeated holds. Target speed is capped at 12°/s and trajectory
acceleration at 40°/s², with braking before the fixed travel boundary.
Holds have no duration cap while the button remains held and heartbeats continue.
The former 20-second cap was removed at the operator's request. Confirm room for ±15° of wrist/cable rotation
using the page's clearance checkbox before holding the button.
The initial 1°/s trial showed a steady ~68 ms control cycle but substantial target
lag on hand reversals. After physical direction confirmation, the cap was raised
to 3°/s, the leader polling pause reduced to 20 ms, and the follower loop pause
reduced to 5 ms. The operator then explicitly requested substantially wider
bounds after the measured motor-speed guard tripped at 8°/s. The present limits
are ±15°, 12°/s target speed, 35°/s measured-speed cutoff, 4° tracking-error
cutoff and 2° measured envelope margin. The trajectory ramps acceleration;
MIT gains remain unchanged. All six follower position/status checks are retained.
Actual cycle duration, leader sample age, trajectory velocity and motor-reported
velocity are logged; speed faults now include the triggering measured value.
The operator confirmed the expanded wrist trial worked well. The recorded trial
reached 14.22° measured travel and 21.41°/s peak motor-reported velocity without
a reported fault (`outputs/wrist_follow_20261002T211544376166Z.jsonl`).
Release, Escape, browser blur/hiding, a 400 ms heartbeat expiry, stale leader or
camera frames, a control cycle over 300 ms, or a tracking fault ends following.
Release removes torque without an automatic return to center. Keep the arm
supported and its physical power switch accessible. Software stop depends on a
responsive process/transport; it is not a safety-rated emergency stop.

The wrist must already be in the MIT mode used by the successful independent
wave. On first hold, its communication timeout is set to 500 ms in RAM and read
back before enable; the previous timeout is restored on clean server shutdown.
The raw timeout register uses 50 µs ticks: 500 ms reads back as 10,000.
`--check-timeout` verifies setup and restoration without enabling any motor,
then exits (stop the dashboard before running it).
No zeros, flash parameters, or other motor settings are written. Motor API
reference: [MotorBridge Damiao API](https://github.com/motorbridge/motorbridge/blob/main/motor_cli/DAMIAO_API.md).
Faults latch until server restart; reconnects cannot resume motion. Both cameras,
leader input, and six follower positions are monitored. Target/measured offsets
and events are logged in `outputs/wrist_follow_<session>.jsonl`.
This does not validate whole-arm following, gripper mapping or camera geometry.

### Guided camera-versus-joint check

The axis dashboard now opens a four-view camera guide: starting view, wrist roll,
wrist yaw, and wrist bend. Keep the tag and robot base fixed. Use **All joints
follow**, briefly press Follow, then release to powered hold. Click **Capture
when steady** once; it waits for a usable view instead of requiring repeated
clicks. For each later view, move the highlighted wrist joint 6–15° in either
direction using the leader, release, and capture. A schematic, live movement
bars, tag quality, settling progress, and saved-view thumbnails show progress.
Coupled movement is included in the forward-kinematics comparison.

Capture requires fresh joint readings and a stationary arm (powered hold or external support),
a continuous one-second image-time stationary window (joint span ≤0.25°), stable camera
poses, and joint readings bracketing the image timestamp. Camera timestamps are
mapped from the SDK host clock to Python's monotonic clock. Joint reads are
sequential host-timed transactions, not hardware-synchronized exposures; the
stationary checks bound this limitation. Measured video delays up to 1.5 seconds
are handled by bracketing exposure timestamps in joint history and requiring
stationarity from that image window through the present; delayed images are never
paired with a newly moved pose. The page displays image delay. Invalid/ambiguous tag estimates and
stale streams prevent capture. Capture actions never enable or move motors.

The dashboard uses NV12 camera transport at 10 fps, retaining 1280×800 wrist
images and using 640×400 for the workspace preview. On the current shared USB 2
connection, the measured median wrist image age fell from 762 ms to 98 ms, and
workspace age from 1053 ms to 46 ms. Wrist intrinsics, calibrated focus (76), and
sensor coordinates were unchanged. `camera_latency_probe.py` reproduces the
camera-only comparison after stopping other camera clients; measurements are
saved in `outputs/camera_latency/report.json`. These are host image-age measurements,
not end-to-end browser display latency.

`outputs/camera_checks/<session>/report.json` and four annotated images preserve
the measurements. Starting a new check preserves earlier sessions. The result
compares relative rotation magnitudes, which do not require a known rigid camera
mount transform; differences over 2° are flagged for investigation. Agreement
is diagnostic only: it does not validate rotation direction, translation,
hand-eye calibration, stereo depth, or fingertip geometry. No calibration files
are changed. Workspace-image rotation is presentation-only.

Completed checks can be reviewed after restarting the dashboard by adding
`--camera-report outputs/camera_checks/<session>/report.json`. Only completed
checks from the same geometry are accepted; loading one does not reuse old
camera frames, apply calibration, or enable motors. Start over begins a new check
while preserving the old report and images.

`camera_alignment_trial.py` provides a separate bounded diagnostic for the
authorized clear workspace and supported folded pose. Stop the dashboard before
running it. Without arguments it previews an example without hardware access.
With `--execute`, it keeps the base, shoulder, and elbow at their starting angles,
moves roll +8°, yaw +8°, and bend −8°, captures stationary views, then reverses
the wrist path and removes torque at the starting folded pose. Targets are limited
to 4°/s and 12°/s². Fresh motor status, temperature, measured speed, tracking error,
camera freshness, existing joint limits, and a small local envelope are checked.
Capture uses measured joint angles, with the same stationary-window checks as
the dashboard. A settling timeout with healthy feedback attempts the reverse
path; a motor/control fault invokes torque-off cleanup. The script is not a
general home planner or collision checker. Wrist joints may settle slightly after
torque removal; both pre-release and final readings are recorded.

`--execute --recover-trial outputs/camera_diagnosis/autonomous_trial_<session>.json`
returns only wrists to that trial's start, rejecting displacements over 10° or
large-joint changes over 0.1°. It holds the large joints at their current angles.
It requires the same supported folded pose and hardware exclusivity. Reports are
saved under `outputs/camera_diagnosis`; no motor zeros, flash settings, or camera
calibration are written.

The OAK-D Lite's BMI270 was verified operational. `camera_alignment_trial.py
--execute --imu` records its raw gyro and accelerometer at 100 Hz alongside the
camera and arm readings; IMU firmware updating is explicitly disabled. Add
`--bend-repeat` for outward/return/repeated bend measurements with all other joints
fixed. `imu_camera_analysis.py <trial.json>` integrates body-frame gyro samples,
subtracting interpolated stationary endpoint biases and rejecting gaps over 30 ms.
Gravity tilt is a separate check; it does not measure yaw. The resulting
`imu_comparison_<session>.json` appears in the dashboard when that completed camera
report is loaded, including a visual comparison of motor, image, and gyro angles.

October 4 independent results changed the diagnosis: the bend-only trial reported
8.01°, 8.03°, and 8.04° from motor readings, but the camera-body gyro measured
6.14°, 6.19°, and 6.19°. Tag estimates differed from gyro by only 0.02–0.35°;
gravity tilt was 6.42–6.46°. This establishes a physical motion discrepancy for
this pose, without identifying a particular mechanical cause. The user's selected
approach is to treat camera measurements as the reference and calibrate the
motor-to-motion mapping. A local bend scale of 0.787 camera degrees per motor
degree fits the outward/return/repeat set within 0.22°, but leaves up to 1.54°
error in earlier wrist poses. This candidate is saved in
`outputs/camera_diagnosis/camera_reference_scale_candidate.json`; it is not an
active global correction. More paired observations across pose and direction are
needed to distinguish a stable mapping from history-dependent motion. Mechanical
inspection is not established as a prerequisite by these measurements.
Original raw images and stationary pose estimates are now
saved with captures for further analysis. Higher resolution and alternate corner
detectors did not consistently remove the discrepancy.

### Autonomous camera-referenced joint measurements

`calibrate_joint_motion.py` previews a bounded route; `--execute` collects it
using both cameras and all six arm motors. Stop the dashboard first so only one
process owns the hardware. Starting near the folded reference, each joint moves
at most 8° at 3°/s with the other joints held, then returns before the next joint.
Fresh camera views, motor feedback, existing joint limits, tracking error, speed,
and temperature checks remain active. Captures use the same stationary gate as
the dashboard. Original images, measured poses, motion logs, return verification,
and motor-off verification are saved under `outputs/joint_calibration/<session>`.
No motor zeros, firmware, global kinematics, or live following mapping are changed.

The default sequence fits separate outward/return angular curves from five views
and tests four additional views. `--dense --joints 5 6` instead fits full camera
rotation with 2° knots and tests intermediate positions in both directions: nine
training views and ten validation views per joint. Rotation interpolation follows
the shortest path between measured orientations. Validation views never enter
the fit. Saved models are local to the recorded reference pose and motion
history; prediction helpers reject extrapolation.

October 4 autonomous runs captured 110 views. Base, shoulder, elbow, and bend
passed local projected-angle checks with largest held-out errors of 0.18°, 0.57°,
0.44°, and 0.71°. Yaw and roll candidates had full-rotation errors of 0.81° and
1.11°, exceeding the unchanged 0.75° target. They remain unvalidated candidates.
These are two different error metrics, not six full-workspace accuracy claims.
All three runs returned to their folded starting pose before motor-off verification.

Load the visual six-joint report with:

```bash
.venv/bin/python axis_follow.py --pairing calibration/leader_pairing_20261002T202428971124Z.json --joint-calibration calibration/camera_joint_motion_summary_20261004.json
```

The panel shows measured curves, separate validation points, tested raw ranges,
and earlier wrist trials. Loading a report checks its geometry fingerprint and
does not enable motors or apply its corrections to live control. The aggregate
report links every original measurement file. Full workspace, absolute joint
zero, hand-eye translation, and fingertip calibration remain separate work.

### Leader following with powered pause

```bash
.venv/bin/python axis_follow.py --pairing calibration/leader_pairing_20261002T202428971124Z.json
```

Stop other arm/camera clients first. The local dashboard starts with **all motors
disabled**, **All joints follow** selected, and wrist yaw selected for inspection.
The gripper is never registered or commanded. No saved absolute pose is replayed.

Press and hold to follow. **Release, Escape, browser blur, heartbeat expiry,
or stale leader/camera input pauses following and holds the measured position
with motor power on.** The motor thread continues checking feedback and sending
hold commands independently of the browser, leader, and cameras. Input recovery
does not resume motion: a new press captures a fresh leader reference. You can
move the leader while paused to reposition it without moving the follower.
There is no duration cap while following or holding.

**Pause is not torque-off.** To remove motor power, physically support the arm,
check the separate support checkbox, then use **Remove motor power**. Motor faults,
tracking/velocity/temperature violations, a stalled motor loop, server shutdown,
or controller/USB/power failure can still remove torque and let the arm drop.
Powered holding depends on a functioning motor controller; it is not a mechanical
brake or a guarantee against falling. Support must remain available.

| Axis | Local range | Target speed | Target acceleration | Measured speed cutoff |
| --- | --- | --- | --- | --- |
| Base, shoulder | ±60° | 18°/s | 60°/s² | 60°/s |
| Elbow | ±90° | 18°/s | 60°/s² | 60°/s |
| Wrist bend, yaw, roll | ±45° | 24°/s | 80°/s² | 75°/s |

These expanded settings passed offline tests; they still require a supported
physical trial. Ranges are intersected with the existing model limits and shown
in the dashboard. They do not establish self-collision, workspace, or cable
clearance. A starting pose up to 1° outside a software model limit may be held
where it already is, but targets can only move inward. Larger discrepancies
block setup. Startup encoder variation up to 0.1° is clipped inside the command
range; larger deviations report the affected joint and allowed interval.

The incremental leader mapping discards excess movement beyond a limit instead
of accumulating an unreachable target. Reversing the leader moves the requested
target inward immediately (the bounded trajectory still accelerates/brakes).
Rows display **AT LIMIT**. Pause/resume re-establishes the leader reference without
expanding follower bounds. Changing selection or mode while disabled captures a
new starting window; reversing a direction preserves that window.

Target smoothing uses an 80 ms response constant. Non-roll motor velocity commands
allow 1.5 times target speed for catch-up. Tracking error is limited to 8°, and
measured positions must remain within 2° of the command envelope. Motor feedback,
temperature checks, and the 500 ms motor watchdog remain active while paused.

**Selected joint only** powers only that joint; all other links require external
support and may drift no more than 2°. **All joints powered · selected joint
follows** holds the other five positions. **All joints follow** accepts coupled
leader movement on all six axes. Support and remove power before changing mode,
selection, or direction. Direction confirmation still requires at least 2° of
leader and 1° of follower movement. Saved physical direction overrides are retained.

Roll retains its tested MIT gains. Other axes use position/velocity mode with
`B601_GAINS` on the first three and existing positive gains on bend/yaw. Initial
enabling begins with 0.8 seconds of slow load take-up and a 1° settling check;
leader movement during that period is ignored. Resume from powered pause does
not re-enable motors. Modes, gains, and timeouts are changed only in RAM with
readback checks and restored after torque-off on exit. No zeros or flash writes.
`--check-settings` verifies configuration/restoration without enabling motors.

Logs in `outputs/axis_follow_*.jsonl` distinguish requested pauses, actual powered
pauses, resume, explicit torque-off, faults, and server shutdown. Browser pause
requests include their event reason; heartbeat expiry is identified server-side.
Samples include which joints are limited. Fault cleanup attempts to disable every
attempted/active motor even when one disable fails. A failed cleanup is reported
as an attempt, not confirmation that motor power is off.

Dependencies are installed in `.venv`; `uv.lock` pins them. To recreate: `uv sync`.

The OAK and B601 serial controller need Linux USB permissions configured. Run once:

```bash
bash scripts/setup_usb.sh
```

Enter your sudo password in your terminal. Reconnect the OAK if necessary, then:

```bash
uv run hello_world.py --preview
```

### Migration to this computer (September 30, 2026)

Current camera roles are OAK-D-LITE `19443010C104077E00` on the wrist and
OAK-1 `19443010A155785A00` on the tripod, recorded in `config/cameras.json`.
Arm demos, tag observations, and hand-eye capture explicitly select the wrist
camera and refuse to substitute the tripod if it is unavailable. The earlier
OAK-1 wrist camera documentation below describes the previous setup. Saved
hand-eye candidates and prior physical route verification must not be assumed
valid for the current camera and mounting. Start a new hand-eye session when
collecting measurements with this setup.

Wrist previews and saved viewing images rotate 180 degrees for the upside-down
mount. Labels are drawn upright after rotation. Raw calibration images, depth
arrays, tag coordinates and metric estimates retain original sensor coordinates;
reports identify the display rotation. Offline `tag_view.py --image` leaves the
supplied image orientation unchanged.

The locked Python environment and pinned DM URDF have been restored. The URDF
fingerprint matches the saved hand-eye capture dataset. All 44 offline tests pass,
and `continuous_approach.py` previews successfully. The most recent documented
hardware experiment was the continuous noncontact lift/scan/approach/return below.
Contact and hand-eye validation remain unresolved.

USB enumeration finds the HDSC arm controller at the existing persistent serial
path, one Luxonis OAK device, and a CH340 serial adapter. Joint reads and camera
capture currently fail on device permissions. `scripts/setup_usb.sh` now covers
both the OAK and this specific HDSC controller, using your account's primary group.
Run it in your terminal with your sudo password, then perform read-only checks:

```bash
.venv/bin/python calibrate_arm.py inspect
.venv/bin/python tag_view.py --seconds 5 --output outputs/migration_tag.jpg
```

No motors were enabled during migration. Before replaying a taught route or
executing a lift, establish the current supported starting pose and tag/base
placement. Saved observations do not establish their positions after relocation.
The recreated interpreter is stored in ignored `.python/` so it survives temporary
directory cleanup. Previous ignored `outputs/` run telemetry was not included in
this checkout.

### OAK-D Lite stationary revalidation (October 1, 2026)

`revalidate_setup.py` reads the disabled arm before/after capturing synchronized
RGB and RGB-aligned stereo depth, excluding 30 warm-up frames. The current setup
passed: 60/60 tag detections, 100% valid depth in the tag interior, approximately
3 mm median stereo/tag-plane disagreement, 0.43 mm tag Z sample variation, and
less than 0.6 ms RGB/depth timestamp difference. Joint positions did not change.
These checks use the configured 60 mm tag size; they are consistency measurements,
not independent dimensional or hand-eye validation. All 47 offline tests pass.

Summary: `calibration/wrist_setup_validation.json`. Original measurements and
images: `outputs/wrist_revalidation/`. Current RGB-only observation check:

```bash
.venv/bin/python tag_pose.py
```

The current arm pose is outside the lift demo's five-degree reference tolerance.
Physical route validation and camera-to-wrist calibration remain incomplete for
the new mount. Hand-eye sessions now record camera identity and reject resuming
legacy samples or samples from another camera. To collect a new session in an
attended terminal, keep the tag/base fixed, manually support the disabled arm,
and capture at least 20 distinct stationary views with varied wrist orientations:

```bash
.venv/bin/python calibrate_camera.py capture --new-session
.venv/bin/python calibrate_camera.py solve
```

Space captures a pose; Q finishes. `--new-session` archives the old sample JSON
and preserves its images. The solver still requires held-out errors within
5 mm and 2 degrees and does not enable motion.

The October 1 OAK-D session `20261001T234501896017Z` contains 20 poses with
useful rotation diversity. Its held-out translation errors are 12.31, 5.55,
26.35 and 10.34 mm; orientation errors are 1.46, 0.79, 0.67 and 0.85 degrees.
Position validation fails. Training-only corner refinement also fails and is
preserved as a diagnostic candidate; neither candidate is activated. Verify
tag/base stability, measured black-square size, rigid flat backing, camera mount
rigidity and physical joint reference before prescribing a replacement session.
The original capture images remain available; review montage:
`outputs/handeye_review.jpg`.

The operator confirms the black square measures 60 by 60 mm, is mounted on a
rigid flat board and stayed fixed. A fresh 12-sample stationary check measured
less than 0.07 mm translation standard deviation per axis and unchanged joint
readings. Choosing before versus after joint readings does not resolve the
held-out error (maximum approximately 25.9 versus 26.9 mm). Small training-only
reference-offset and scale adjustments also fail; these diagnostics do not modify
the arm reference or activate a transform. The root cause remains unresolved.
Next compare the physical arm and camera mount against the recorded reference
and model; repeating an unchanged full capture session is not yet prescribed.

The supported reference check showed shoulder/elbow/wrist-bend differences from
the saved reference of approximately 0.32/0.003/0.19 degrees; the reference was
not overwritten. The operator also confirms the robot base was securely fixed.
The OAK-D Lite RGB sensor has autofocus, with observed lens positions changing
while its intrinsic metadata remained constant. Both stored and factory
calibration specify lens position 76. `config/cameras.json` now pins that focus;
RGB clients apply it in RAM after startup and hand-eye captures record actual
lens position. Sessions from the previous autofocus configuration cannot resume
into a fixed-focus session. This may contribute to calibration error, but is not
yet established as the sole cause. RGB-only manual-focus capture works. Full
hand-eye and motion validation remain incomplete. Focus changes do not write
camera EEPROM or motor settings.

USB reconnection did not resolve DepthAI 3.10's stereo-source firmware assertion.
The same IMX214/OV7251 failure is described in Luxonis issue
https://github.com/luxonis/depthai/issues/1252. An isolated DepthAI 2.32 environment
produced 60 synchronized RGB/stereo frames without a crash and with measured
lens position 76 throughout. Main arm dependencies remain on their pinned v3
versions. Reproduce the camera-only stream check:

```bash
UV_CACHE_DIR=/tmp/b601-uv-cache uv venv .venv-depth-v2 --python .venv/bin/python
UV_CACHE_DIR=/tmp/b601-uv-cache uv pip install --python .venv-depth-v2/bin/python -r requirements-depth-v2.txt
.venv-depth-v2/bin/python depth_probe_v2.py
```

`outputs/wrist_depth_v2_native/report.json` shows stable streams, but sparse depth
in the tag region and failed tag/depth metric consistency. RGB/depth alignment
also remains unvalidated. This stream workaround is not an accepted depth
calibration or motion activation. The v3 `revalidate_setup.py` stereo graph remains
available for diagnosis but currently triggers this firmware error on this unit.
After focus locking, the RGB-only 20-observation check measured approximately
0.10 mm Z standard deviation.

The replacement fixed-focus session `20261002T003620145947Z` now contains 20
poses, all verified at lens position 76. Held-out translation errors are 3.97,
7.68, 12.12 and 4.28 mm; orientation errors are 0.81, 0.72, 1.27 and 1.27 degrees.
The worst position error improved from 26.35 to 12.12 mm, but still fails the
unchanged 5 mm limit. Individual tag corner RMS errors are 0.031–0.256 pixels.
Training-only corner refinement also fails and is saved separately in
`calibration/arm2_handeye_fixed_focus_refined_candidate.json`. Before/after
joint-read choice and diagnostic reference-offset fitting do not resolve the
disagreement; reference settings remain unchanged. The operator confirms the
camera mount is firmly fixed with no wobble. Independently measure joint/model
agreement before another full capture.
Review images: `outputs/handeye_fixed_focus_review.jpg`. Current results are
recorded in `calibration/wrist_setup_validation.json`; no candidate is activated
and motion remains disabled.

The camera starts first, followed by a three-second countdown. Joint 6 rotates ±8°
from its measured starting position, twice over 12 seconds, then returns to the
starting target and disables the wrist. Other joints and the gripper are never
commanded. Place the arm in a stable, supported pose and leave room for the wrist
and camera cable. The wrist must initially be disabled; an already enabled wrist
is rejected to avoid taking over another controller.

Press **Q**, **Esc**, or **Ctrl+C** to stop and disable the wrist immediately.
Stopping early does not run a return trajectory. A disabled wrist can rotate under
its load. Keep the hardware emergency stop accessible; software cannot stop a motor
if the USB link or process is lost.

Without `--preview`, the same demo runs headlessly. The latest RGB frame is saved
to `outputs/hello.jpg` on exit. OAK-1 provides RGB, not stereo depth.

## Individual checks

```bash
uv run hello_world.py --mode probe        # Read joint6 only; no enable or mode writes
uv run hello_world.py --mode camera --preview
uv run hello_world.py --mode dry-run      # Print offsets; no hardware access
uv run hello_world.py --amplitude 5 --cycles 1 --preview
uv run python -m unittest discover -s tests -v
```

`--port` overrides the default persistent serial path.
`--output` changes the snapshot path. Amplitude is capped at 10°, period at least
6 seconds, and cycles at most five. The demo checks joint6 travel limits, fault
status, temperature, and tracking error. It is a small joint-space demo, with no
collision planning. The motorbridge state API has no receive timestamp, so cached
feedback cannot prove a live bus connection.

## Implementation references

- [Seeed Python SDK](https://github.com/Seeed-Projects/reBotArm_control_py), inspected at commit `6415d43130d1e143c70dc106096a857ac5556f81`. Reference checkout is in ignored `vendor/`; the demo does not import it.
- DM joint6: motor ID `0x06`, feedback `0x16`, model `4310`, MIT gains Kp=18/Kd=2, URDF limits ±3.14 rad. The demo adds a 0.1 rad limit margin.
- [Luxonis Camera API](https://docs.luxonis.com/software-v3/depthai/depthai-components/nodes/camera/)
- [Luxonis Linux USB setup](https://docs.luxonis.com/hardware/platform/deploy/usb-deployment-guide)

## Verification on this machine

Serial feedback from joint6 succeeded (about 8.86°, disabled, 27°C MOS / 25°C rotor).
Motion bounds and cleanup tests pass. Live camera capture and the physical wave
remain unverified until the OAK USB permission rule is installed. The demo fails
before enabling the wrist when the camera is unavailable.

## AprilTag detection (no arm motion)

```bash
uv run tag_view.py --preview
uv run tag_view.py --image outputs/tag_initial.jpg
```

Searches for ID 0 in the four OpenCV AprilTag dictionaries (or specify
`--family 36h11`). Saves an annotated image and JSON corner coordinates. Detection
is in pixels only; it does not establish a metric gripper target or confirm contact.
Synthetic marker tests cover all four families and rejection of other IDs.

The initial live image did not contain a detected tag. Full-arm lift/search and
contact are pending the tag dimensions, camera-to-tool calibration, and resolution
of the joint coordinate mapping: measured joint2=+0.981 rad and joint3=+1.765 rad,
while the inspected DM URDF limits both to [-3.14, 0]. No arm motion was commanded
during this inspection. Do not negate these angles without verifying the physical
joint directions and calibration offsets.

Tag settings are now saved in `config/tag_task.json`: family **36h11**, ID **0**,
side **0.060 m**. `tag_view.py` defaults to that family and ID. The teaching tool
was found at `/home/chris/rebot-hello/teach_ranges.py`; its range file is copied to
`config/taught_joint_ranges.json` with the source path recorded. It contains raw
motor travel ranges, not joint-to-model offsets, hand-eye calibration, or a taught
20 cm lift. Those missing transforms remain explicitly unset. The older folder
also describes a second arm, so the range file's physical-arm identity needs to
be resolved before using it to bound arm motion.

The connected arm is confirmed by the user to be the **second arm**. The expected
`/home/chris/rebot-hello/joint_ranges_arm2.json` was not found. The copied first-arm
ranges are therefore excluded from the active task configuration. A recollection
that the elbow test raised the gripper is not a measured Cartesian calibration.
Before autonomous lift/contact, establish this arm's joint-to-model mapping and
camera-to-gripper/contact-point geometry. A manually supported viewing pose with
the tag visible allows camera/tag observations without guessing a lift trajectory.

## Metric tag observation

`uv run tag_pose.py` captures 20 observations of the configured 60 mm tag with
per-frame OAK intrinsics and distortion metadata at 1280×800. It saves
`outputs/tag_pose.json` and an annotated image. Each sample retains both planar
pose candidates when valid; estimates are in the camera frame (x right, y down,
z forward), not the robot base or fingertip frame. No motors are accessed.
A synthetic projection test checks scale, distortion handling, and corner order.

The user manually raised the second arm; its read-only joint snapshot is saved
in `outputs/arm_raised.json`. Tag36h11 ID 0 was detected in that view, saved as
`outputs/tag_raised.jpg`. This observation does not establish a safe replay path
or a calibrated contact point.

A subsequent supported capture succeeded: 20 usable observations put tag 0 at
approximately (0.0576, 0.0236, 0.2445) m in camera coordinates. Across these frames,
translation standard deviations were (0.00088, 0.00050, 0.00321) m; these measure
sample variation, not absolute accuracy. The tag pose and image are in
`outputs/tag_pose.json` and `outputs/tag_pose.jpg`. The separately read joint
snapshot is `outputs/arm_held.json` and is not time-synchronized to the images.
All motors remained disabled and no movement commands were sent. Metric camera
observation is verified; fingertip contact and Cartesian control remain uncalibrated.

## Second-arm software reference calibration

See [the calibration procedure](calibration/README.md) and the included official
[reference photograph](calibration/seeed_reference_pose.jpg). Run
`uv run calibrate_arm.py reference` only while manually supporting the arm in that
reference pose. The tool records software calibration candidates, never writes
motor zeros or enables motors, and leaves motion blocked pending validation.
`uv run calibrate_arm.py inspect` reads current positions without saving a pose.

## Lift, find tag 0, and approach without contact

The current demo is `rise_approach.py`:

```bash
uv run rise_approach.py             # geometry preview; no hardware access
uv run rise_approach.py --execute   # attended physical run
```

Start with the second arm near its folded resting reference, tag/base fixed,
and the space above/in front clear. The first centimeter moves slowly and settles
so the wrist takes the load; the remaining lift and camera scan use a 0.06 rad/s
trajectory limit, six times the initial demo's 0.01 rad/s. Faster motion is blocked
until that load take-up completes. The 1-degree tracking limit remains in force.
The camera scans downward until tag36h11 ID 0 is reliably visible. `APPROACH`
performs a 2 cm noncontact move, with observations after each 5 mm step; `REST`
returns without approaching. It returns along the executed path afterward.

`arm_control.py` applies the supplied B601 position-loop settings to the three
large arm motors in RAM, retains the existing wrist settings, verifies each write,
and restores the original gains when stopping. No motor zero, protection or
flash settings are written. Correction-speed headroom is separate from the
trajectory's movement speed.

The full hardware run completed a commanded 20 cm lift, 25-degree downward scan,
and 2 cm approach. The observed camera-to-tag range decreased from 407.9 mm to
390.4 mm. This verifies a short approach; it does not calibrate fingertip contact.
Images, tracking samples and the run result are saved under `outputs/rise_*`.

### Faster run and closer approach

```bash
uv run fast_approach.py             # preview without hardware
uv run fast_approach.py --execute   # attended faster run
```

This retains the slow first centimeter and two-second settling interval, then
ramps native waypoint speed limits through 0.09, 0.12, 0.18 and 0.24 rad/s.
The maximum is four times the preceding demo's 0.06 rad/s travel limit; startup,
settling and camera observations still take their own time. `waypoint_motion.py`
checks measured deviation from each bounded joint-space segment against a
1-degree limit, along with speed, fresh feedback, endpoint settling and timeout.
It also refuses faster moves before the load take-up completes.

The camera continues tilting until the full tag is near its center. After
`APPROACH`, this version advances up to 6 cm in 5 mm steps, stopping early on
observation loss, a workspace limit, or the 25 cm camera-to-tag-plane standoff.
The approach remains slower than free-space travel. The executed path is reversed
before shutdown. This is still a noncontact demo.

The first full faster run reached the 0.24 rad/s waypoint setting, centered tag 0
at 40 degrees of downward tilt, and completed the 6 cm approach. Measured
camera-to-tag range decreased from 379.3 mm to 318.1 mm. Results and waypoint
telemetry are in `outputs/fast_approach_result.json`.

### Continuous lift and approach

`uv run continuous_approach.py` previews without hardware access; `uv run continuous_approach.py --execute` runs the supervised route from folded rest. It blends a 20 cm lift, 40° camera tilt, up to 6 cm noncontact approach, and return without waypoint dwells. The first centimeter takes up load gently while monitoring stability. Free-space speed is capped at 0.48 rad/s, with acceleration limiting and an earlier slowdown during the final camera tilt to acquire eight fresh tag observations. Vision, clearance, joint bounds, and 1° path-deviation checks remain active; missing vision causes a return. Do not move the tag or base, obstruct the taught workspace, or run another motor/camera client during execution.

Verified hardware run: completed 6 cm approach and returned in 49.35 s, measured peak joint speed 0.337 rad/s and maximum path deviation 0.481°. Camera-to-tag range at the approach endpoint was 324 mm (camera-to-tag-plane distance 303 mm). All six arm motors were verified disabled and original gains restored afterward. This is a noncontact demonstration, not a verified fingertip contact routine. The doubled speed cap does not mean the whole cycle runs twice as fast. Results: `outputs/continuous_result.json`; endpoint image: `outputs/continuous_closest.jpg`. All 44 offline tests passed before this run.

### October 4: faster stereo approach and first confirmed tag touch

The current camera-controlled runner is `camera_visual_approach.py`. It uses the
working `AxisArm` controller, the calibrated/fixed-focus RGB view for the first
20 cm, then the OAK-D Lite B/C stereo pair for incremental fingertip positioning.
The operator witnessed the padded fingertip touch the AprilTag paper on October 4.
The complete run returned to folded rest and verified all six arm motors off.
Contact record: `calibration/first_confirmed_tag_touch_20261004.json`;
full telemetry: `outputs/visual_approach/20261004T200403261403Z/report.json`.

```bash
# Preview only (default):
.venv/bin/python camera_visual_approach.py --fast --forward-m .20 --bend-view 6
# Clear workspace, same fixed arm/tag/camera/gripper setup, no competing clients:
.venv/bin/python camera_visual_approach.py --execute --fast --forward-m .20 --bend-view 6 --stereo-servo
# Explicit bounded touch attempt, followed by retraction:
.venv/bin/python camera_visual_approach.py --execute --fast --forward-m .20 --bend-view 6 --stereo-servo --touch
```

Fast traversal merges waypoints only when their joint-space chord differs by at
most 0.2 degrees from the dense route. It preserves the initial viewing pose and
lift corner, reduces stationary captures from 52 to four, and requests at most
12 degrees/s with 36 degrees/s² acceleration. Measured-motion pacing reduces
speed when tracking lag grows. The free-space tracking limit is 4 degrees;
stereo traversal restores the 2-degree limit and slower settings. The verified
20 cm waypoint was reached in about 40 seconds including camera startup, versus
164 seconds in the preceding capture-at-every-5-mm run. The complete touch run
kept motors enabled for 190 seconds; maximum recorded tracking error was 2.294
degrees. Near the paper, steps decrease to 0.5 mm with a 1 degree/s joint cap.
These are phase-specific settings, not global teleoperation changes.

`stereo_contact_observer.py` runs in `.venv-depth-v2` (DepthAI 2.32), publishing
fresh, synchronized, metric B/C tag poses. At the tested 20 cm endpoint, tag-edge
errors were below about 0.4 mm. DepthAI 3.10 simultaneous RGB/mono capture crashed
the device during motor-off diagnostics; RGB alone works. No firmware or EEPROM
was changed. The v2 RGB preview's intrinsic metadata did not describe its actual
crop; stereo control therefore uses B coordinates directly. Diagnostic evidence
is under `outputs/contact_camera/20261004T190921818454Z` and
`outputs/contact_camera/20261004T194430628210Z`.

The touch target is the white border 5 mm beyond the black square, preserving
stereo visibility. Contact occurred with the candidate fingertip landmark still
reporting about 5 mm clearance; camera advance stalled and motor load changed.
The operator confirmed physical touch. The exact onset and force were not
measured, so the saved contact is a calibration observation, not a globally
validated fingertip/hand-eye transform. Final approach never requests penetration
past the estimated paper plane, checks both fingers, and retracts on visibility
loss, near-paper stalled advance, or load change. The stalled-advance guard and
closest-view snapshots were added after the confirmed touch run and passed
offline checks; they have not yet been exercised on another hardware run.

The longer-settling wrist refinement did not pass: roll held-out full-rotation
error was 1.94 degrees, and the yaw repeat lost tag visibility. Previous results
and the unsuccessful repeat remain in the dashboard summary. No local calibration
curve was globally activated. All 141 offline tests passed after these changes.

#### Operator-requested 2× cruise profile

Add `--speed-scale 2` to the `--fast` command for a 24 degrees/s cruise cap and
144 degrees/s² acceleration. Native position/velocity motor command limits remain
27 degrees/s for the first three axes and 36 degrees/s for wrist bend/yaw.
Measured-speed protection is 40 degrees/s for this run, below the existing
teleoperation profiles. The known free-space route permits 6 degrees tracking
error and paces at 4.5 degrees lag; stereo uses tighter limits, and final contact
retains the previous slow/small-step settings. Three-frame stereo checks replace
seven-frame checks only during the coarse approach; final approach still uses
seven frames. Load changes pause advancement immediately and require three
settled readings before ending the attempt.

Hardware run `outputs/visual_approach/20261004T201108905356Z/report.json` completed
the route and returned with all six motors verified off. Peak shoulder speed rose
from 7.29 to 13.94 degrees/s; elbow from 7.48 to 12.85 degrees/s. Maximum measured
joint speed was 19.62 degrees/s and maximum tracking error 4.463 degrees. This
run retracted on the load guard at 9.03 mm candidate-landmark clearance; a second
physical touch was not confirmed. The prior run remains the operator-confirmed
contact. Enabled duration was 126.5 seconds versus 190.3 seconds previously, but
these whole-cycle times include different final-approach endpoints, so they do
not establish a 2× complete-cycle speedup. All 142 offline tests pass.

#### 48 degrees/s noncontact trial (another requested doubling)

`--fast --speed-scale 4 --forward-m .20 --bend-view 6` is restricted to the known
noncontact route. It ramps the viewing/lift portion at 36 degrees/s, then requests
48 degrees/s at 288 degrees/s² on forward/return travel. A transient per-command
native velocity ceiling of 60 degrees/s is set only on this trial's AxisArm
instance (first five joints); normal dashboard defaults, motor gains and flash
remain unchanged. Measured-speed protection is 60 degrees/s. Tracking protection
is 8 degrees, matching the existing teleoperation tracking ceiling. A bounded
trajectory-clock advance reserves 0.5 degrees below that ceiling without changing
the joint-space segment. The profile rejects stereo/contact options so this
experiment does not propagate the new speed to the paper approach.

Run `outputs/visual_approach/20261004T201749820363Z/report.json` completed the 20 cm
route and return, with all six motors verified off. Shoulder peak increased from
13.94 to 19.98 degrees/s (43%); elbow from 12.85 to 14.44 degrees/s; wrist bend
from 19.62 to 24.98 degrees/s. This did not produce another doubling of actual
speed. Tracking error reached 6.643 degrees; maximum motor temperature was 43°C.
The motors were enabled for 41.8 seconds on this noncontact-only run; that is not
directly comparable with the earlier 126.5-second stereo/contact trial. Short
segments still accelerate, brake and settle individually, and tracking pacing
also limits progress. Smooth waypoint transitions are the next performance
refinement, before further cap increases. All 144 offline tests pass.

Manufacturer reference for configurable native POS_VEL speed limiting:
https://wiki.seeedstudio.com/rebot_arm_b601_dm_pinocchio_meshcat/
Manufacturer load/temperature test reference (V4 hardware; not a certification of
this particular arm/setup):
https://github.com/Seeed-Projects/reBot-DevArm/blob/main/hardware/reBot_B601_DM/performance_testing/Performance_Testing.md
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

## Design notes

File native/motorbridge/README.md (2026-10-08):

# Optional fresh motor feedback

`fast_feedback.py` uses this Linux ABI extension to read six independent motor
transactions concurrently. Motor commands remain on the existing owner thread.
Each position-register reply and status reply must arrive after its request;
cached status cannot satisfy the native transaction. One missing position or
status reply gets one fresh request with a 40 ms timeout; a second failure or a batch over
120 ms faults the controller. All worker reads finish before commands resume
or motor handles close. Temperature, speed and motor-status checks remain active.

The patch adds one exported function to motorbridge 0.5.6, commit
`c652ce420e7da1008fa1864cc7f47d7d7c57fdb6`, and two freshness tests. It uses the
upstream Damiao timestamped feedback implementation. It does not change firmware,
motor gains, acceleration limits or the installed Python package.

With Git and Rust 1.90.0 installed, and motorbridge 0.5.6 in the Python environment:

```sh
python3 native/motorbridge/build.py
.venv/bin/python -m unittest tests.test_fast_feedback
```

The build downloads pinned upstream sources, runs the native tests and writes
`build/libmotor_abi.so` plus a checksum manifest. These generated files are ignored
by Git. `--cargo /path/to/cargo` supports an isolated toolchain. The source retains
upstream's license; see the pinned upstream repository.

The concurrent reader is experimental and **off by default** after sustained
holding exposed communication failures. `AxisArm` uses the original sequential
reader even when the extension is built. `B601_FRESH_FEEDBACK=1` opts into the
experimental reader for explicit investigation; a checksum/source mismatch is
an error. Stop the controller with motors disabled before switching readers.

Read-only hardware timing, with the arm supported and disabled:

```sh
.venv/bin/python scripts/arm_response_probe.py --fresh
```

The first 100-read hardware sample measured 5.19 ms median and 5.45 ms maximum
for all six joints, compared with about 45 ms for the original sequential read.
This measures feedback latency, not arm trajectory completion time.

A subsequent full camera/rail/arm trial completed the unchanged open-jaw route
in 114.14 s versus the previous 129.24 s. Median motion-loop interval was
11.68 ms, maximum tracking error 0.981 degrees, and the arm returned with all
motors disabled. A lost status reply during the initial disabled soak led to
the bounded one-retry behavior above; no cached-response fallback was added.

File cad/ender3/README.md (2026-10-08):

# Ender 3 reference geometry

`Ender3.STEP` is the unmodified Creality Ender 3 reference assembly from
[Creality's repository](https://github.com/Creality3DPrinting/Ender-3/blob/88c7758cea9d0d00a54fdb238bedb3b33425f409/Ender-3%20Mechanical/STP/Ender3.STEP),
commit `88c7758cea9d0d00a54fdb238bedb3b33425f409`. The upstream GPL v3 license is
included in `LICENSE`. The inspection script, derived structural references and
inspection results were added for this project in October 2026.

This model does not include the installed custom syringe drive or certify the
printer's current placement. `inspection.json` records the original file hash.

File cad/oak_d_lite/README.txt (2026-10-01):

REVISION 2 - WRIST CLEARANCE CORRECTION
Use the v2 print file. Revision 1 extended into the wrist clearance and does
not fit. The exact inherited 28.65 mm radius cutout, centered at CAD
X=-0.0009376866, Y=-45.2171488122, now continues through the entire camera
plate. CAD comparison shows 473.77 mm^3 removed inside that clearance and
zero geometry changes outside it. Lower attachment and all fasteners are
unchanged. Fit still needs a physical check. Superseded v1 files are archived
under revisions/v1; do not print them. Unversioned export aliases now contain
this corrected geometry as well.

OAK-D Lite mount for the Seeed reBot B601-DM

PRINT: OAK_D_Lite_B601_v2_PRINT.stl (millimeters, already oriented on the bed).
EDIT: OAK_D_Lite_B601_v2.step or build_mount.py.
VIEW: OAK_D_Lite_B601_v2_preview.png / OAK_D_Lite_B601_v2_assembly.step.
The assembly contains the reference camera. Do not print the assembly or camera.

This replaces the complete installed OAK1_B601_snug_1mm bracket. The proven
arm attachment below CAD Z=25.6 mm is unchanged. The camera plate is now
95 mm wide, with two 4.5 mm clearance holes at 75 mm centers, seven ventilation
slots, and 1 mm raised camera seats. Two rear M4 screws replace the old
OAK-1 tripod screw and anti-rotation wall. The original mount is preserved.

Hardware and installation
- Reuse the existing arm attachment hardware. Install the bracket on the arm
  before adding the camera, for access to the original countersunk screws.
- Use the two REAR M4 camera mounting threads, not the small case screws.
- The printed seating stack is 5.4 mm. Aim for about 3-4 mm of screw projection
  into the camera. M4 x 10 mm screws with approximately 1 mm washers give
  3.6 mm projection; verify free thread depth on your unit before tightening.
  Tighten gently; never force a screw that bottoms out.
- Install the camera as shown: all three lenses face out; the USB port faces
  the open edge above the attachment. Provide a cable slack loop and strain
  relief on the arm so cable load does not twist the camera or snag the wrist.

Print starting point: PETG, 0.2 mm layers, 4-5 perimeters, 35-40% infill.
Use the supplied orientation with the 95 mm tray edge on the bed and a brim
if needed. Inspect the slicer preview: narrow vent roofs bridge 6 mm, and the
original clip and horizontal screw bores may need local support depending on
printer settings. Keep support off the camera seating pads where possible.
Overall print envelope: approximately 95 x 31 x 40 mm. Solid CAD volume 25.3 cc.

Verification
Valid single CAD solid; watertight, consistently wound, single-component STL;
unchanged lower arm attachment; zero interference with the official Luxonis
camera enclosure; M4 bores open and USB plug clearance envelope unobstructed.
The mount stays behind the camera front face. These checks do not certify the
camera field of view past the gripper, the full robot travel envelope, strength,
or print fit. Physically test the fit and inspect clearance before powered use.
The earlier OAK-1 camera-to-wrist calibration must be replaced after fitting
this camera; no robot software/calibration or motor state was changed here.

Rebuild: python build_mount.py (CadQuery 2.8.0, trimesh used for this export).
Optional preview: python render_preview.py (VTK). Reference camera is a Luxonis
STEP model, reoriented using its measured mounting-hole axes. Lens circles in
the PNG are schematic markers; the enclosure geometry is the official CAD.

Source provenance
Installed source: OAK1_B601_snug_1mm.step, copied from the prior local CAD work.
Its original generator chain and Seeed reference STEP are included in source/.
Luxonis official enclosure index:
https://github.com/luxonis/oak-hardware/blob/master/DM9095_OAK-D-LITE_DepthAI_USB3C/Mechanical/README.md
Enclosure downloaded 2026-09-30:
https://oak-files.fra1.cdn.digitaloceanspaces.com/OAK-D-Lite/DM9095_enclosure.stp
Measured official enclosure dimensions: 91 x 28 x 17.45 mm.
Rear M4 axes: (3.5,15.5) and (78.5,15.5), rear seating plane Z=8.5 mm.
Derived mount/source: CERN-OHL-W-2.0, see included license. Third-party camera
reference CAD remains under its upstream terms; it is not a printable part.

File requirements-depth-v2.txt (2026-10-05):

# Isolated camera-only workaround; do not install into the arm's .venv.
depthai==2.32.0.0
numpy==2.2.6
opencv-python==4.12.0.88

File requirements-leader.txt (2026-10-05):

# Isolated optional dependency: install with --target vendor/leader_sdk
motorbridge-smart-servo==0.0.4

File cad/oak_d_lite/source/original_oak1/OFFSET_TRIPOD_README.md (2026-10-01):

# Corrected OAK-1 tripod socket location

This replaces the incorrectly centered camera screw hole in the full-width
attachment revision. Hole diameter remains 6.8 mm. The old central hole is filled;
the new hole is at CAD X=+12.75, Y=5.0 mm. All other geometry is preserved.

Source measurement: Luxonis's OAK-1 enclosure STEP has long-axis bounds
Y=-24.5 to +30.0 mm and tripod thread axis at Y=-10.0 mm. Therefore the socket
is 12.75 mm from the overall enclosure midpoint, toward the USB-C end (14.5 mm
from that end). The camera sits sideways, with its USB-C end toward the mount's
+X edge. In the supplied print orientation this corresponds to the end away
from the build plate. Reverse the camera roll only if using a mirrored hole.

Official CAD link published in Luxonis's repository:
https://github.com/luxonis/oak-hardware/blob/master/BW1093_USB3C/3D_Models/README.md
Enclosure model:
https://oak-files.fra1.cdn.digitaloceanspaces.com/OAK-1/OAK-1_ENCLOSURE.step

The PDF drawing confirms the off-center rear socket but does not explicitly
dimension its offset. The 12.75 mm value is measured from the CAD, not estimated
from the illustration. This applies to the standard USB OAK-1 enclosure.

Print the supplied pre-oriented STL on its long side as before. Full-width
attachment flanges and the single top bar are unchanged. Prior print and hardware
notes apply except any statement that the tripod hole is centered.
CAD validity, closed mesh, filled old hole and open new hole were checked.
Actual fit and printer performance have not been physically tested.

Editable source: build_offset_tripod_mount.py, with the included generator chain
and Seeed reference STEP. Derivative mount source is CERN-OHL-W-2.0 as included.

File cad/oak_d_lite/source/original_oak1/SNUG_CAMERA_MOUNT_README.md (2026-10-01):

# OAK-1 / B601 mount: 1 mm tighter anti-rotation bracket

The single upright anti-rotation wall is moved 1 mm toward the tripod hole:
its inner face changes from CAD Y=24 to Y=23 mm. The perpendicular distance
from the hole centre to the wall changes from 19 to 18 mm.

The offset tripod hole remains at X=12.75, Y=5 mm, diameter 6.8 mm. The wall's
3.5 mm thickness and Z=44 mm top are unchanged. Seating plate, arm attachment,
and print orientation are unchanged. Older designs are preserved separately.

Print OAK1_B601_snug_1mm_PRINT.stl in its supplied long-side-down orientation,
using the same settings and hardware as the previous offset-hole mount.
Test camera fit before tightening; the requested 1 mm adjustment has not been
physically tested. CAD and closed-manifold mesh checks passed, including an
unchanged lower mount and clear tripod bore.

Editable STEP and build_snug_camera_mount.py are included. The script uses the
previous OAK1_B601_offset_tripod.step as its input. Original source chain and
Seeed reference are included in the bundle. Derived design: CERN-OHL-W-2.0.

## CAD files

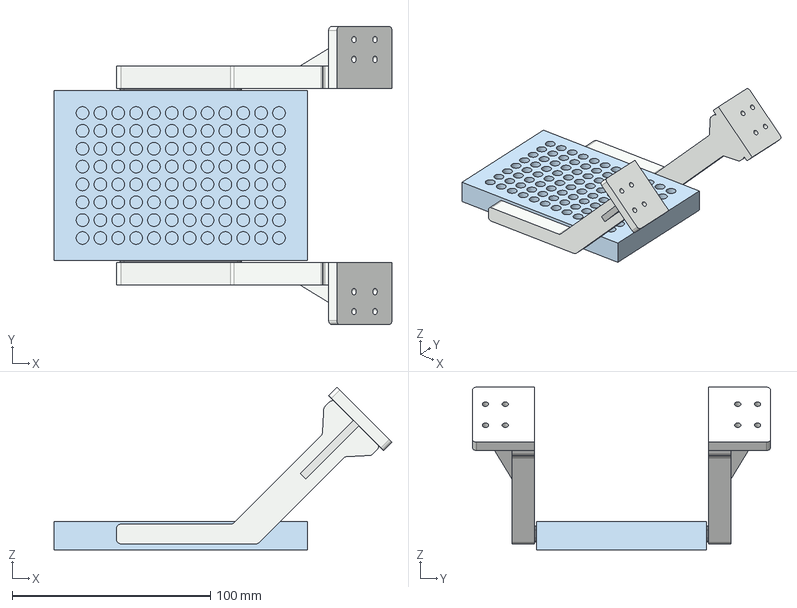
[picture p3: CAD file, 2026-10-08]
cad/grippers/B601_clean_braced45_assembly.step
170.3 x 150.2 x 82.0 mm
LEFT
LEFT_PAD
RIGHT
RIGHT_PAD
REFERENCE_PLATE_NOT_FOR_PRINTING

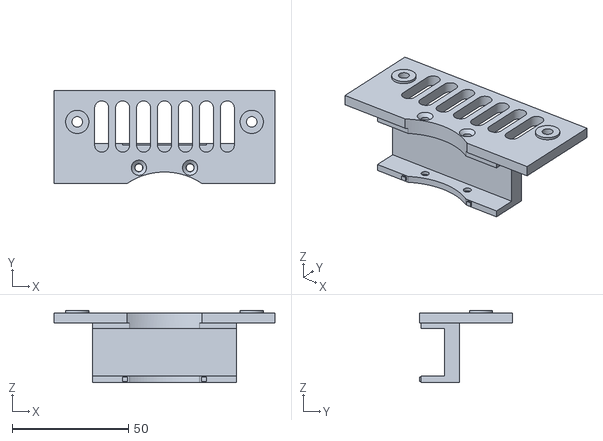
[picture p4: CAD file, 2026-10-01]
cad/oak_d_lite/OAK_D_Lite_B601_assembly_coordinates.stl
95.0 x 40.0 x 31.0

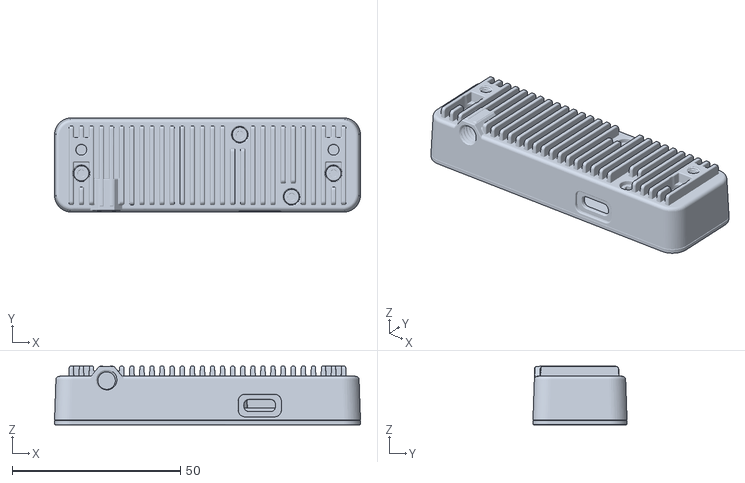
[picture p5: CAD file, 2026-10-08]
cad/cameras/DM9095_enclosure.STL
91.0 x 28.0 x 17.5

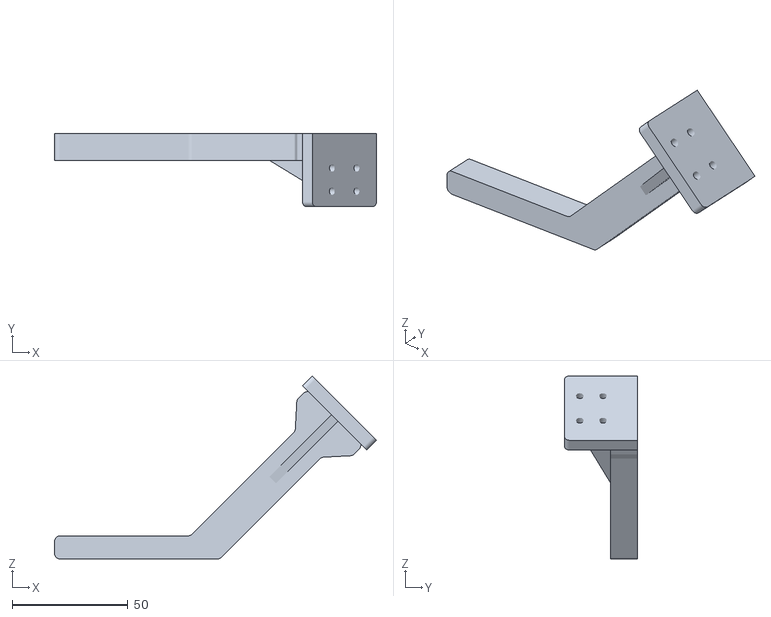
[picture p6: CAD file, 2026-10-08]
cad/grippers/derived/RIGHT.stl
139.0 x 31.4 x 79.0

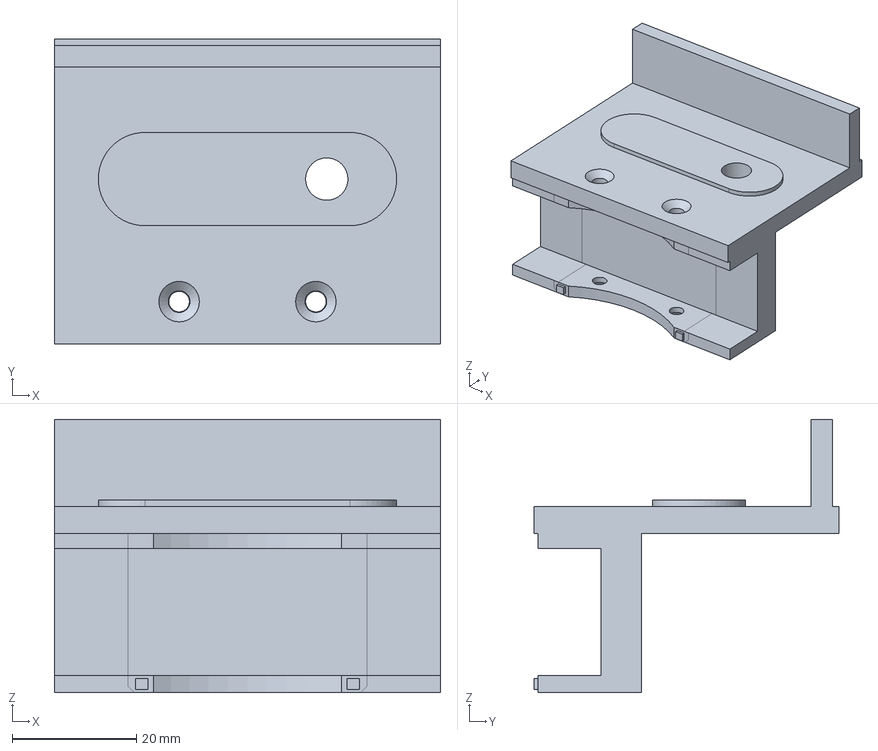
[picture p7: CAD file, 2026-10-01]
cad/oak_d_lite/source/OAK1_B601_snug_1mm.step
62.1 x 49.0 x 44.0 mm

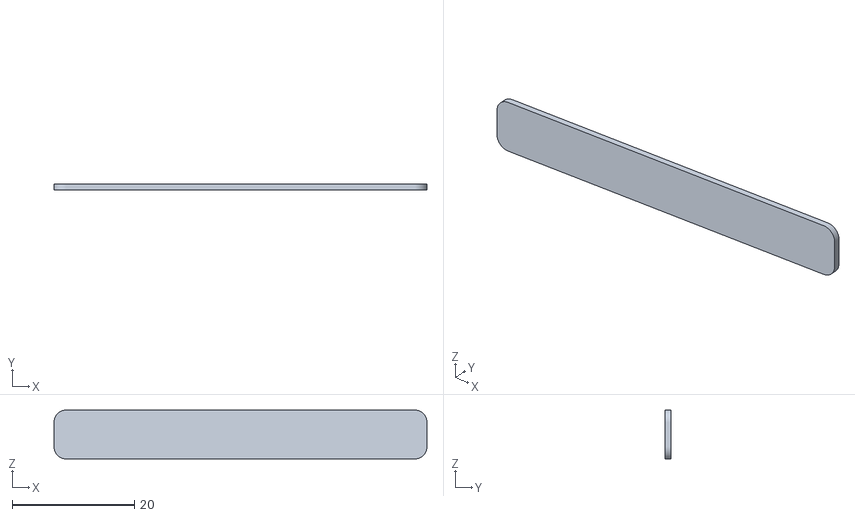
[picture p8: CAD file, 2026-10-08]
cad/grippers/derived/LEFT_PAD.stl
61.0 x 1.00 x 8.00

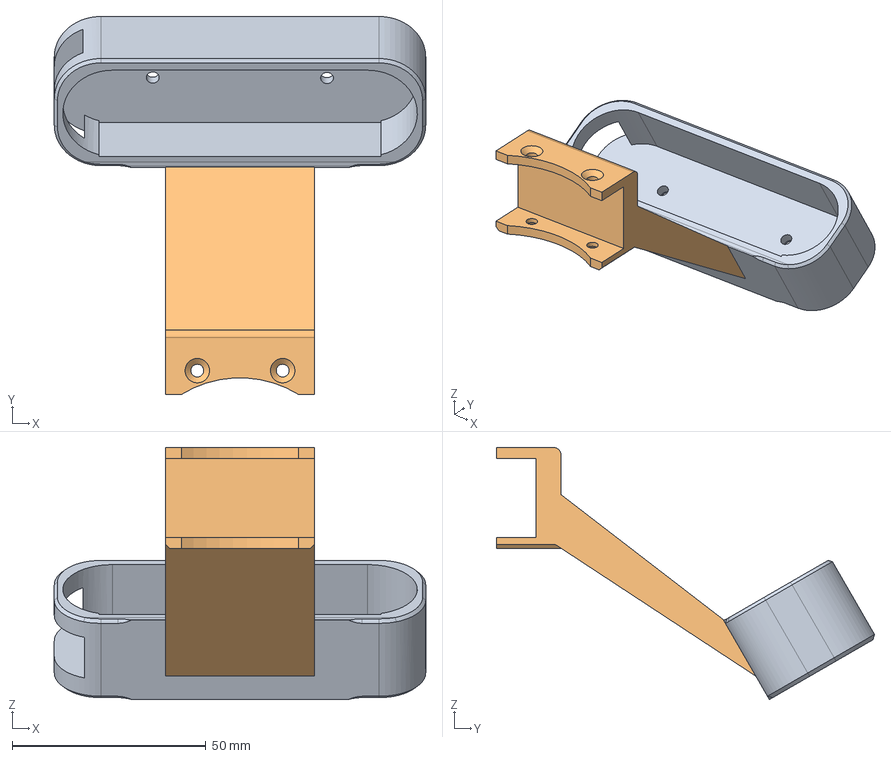
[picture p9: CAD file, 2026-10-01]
cad/oak_d_lite/source/original_oak1/D435_Gemini2_Mount.step
95.8 x 97.4 x 65.0 mm

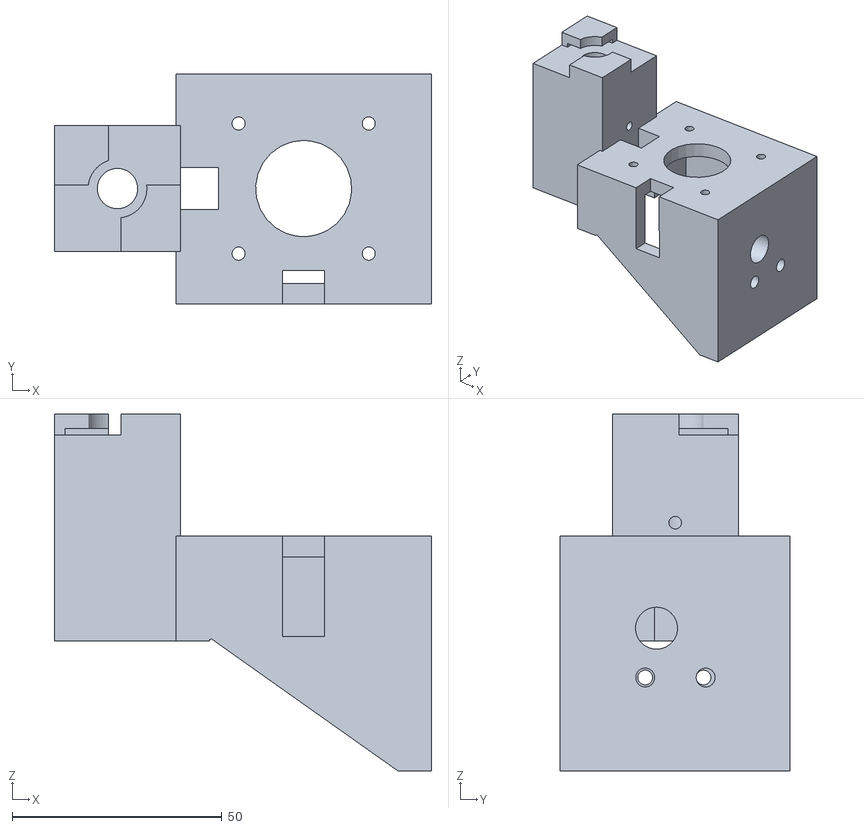
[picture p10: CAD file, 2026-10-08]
cad/printer_bed/liquid_handler_26.stl
89.8 x 54.8 x 85.0

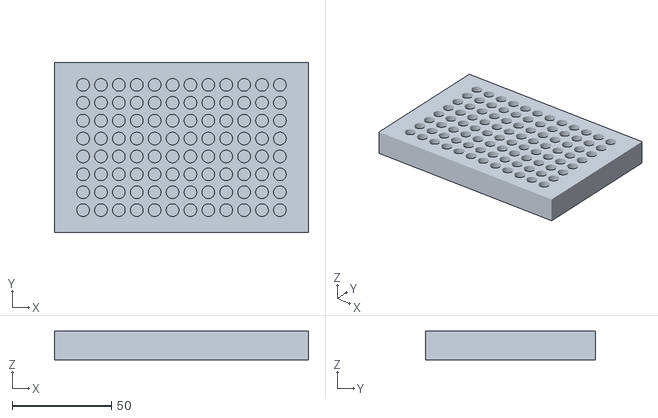
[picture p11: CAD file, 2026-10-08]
cad/grippers/derived/REFERENCE_PLATE_NOT_FOR_PRINTING.stl
127.8 x 85.5 x 14.4

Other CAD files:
cad/oak_d_lite/revisions/v1/OAK_D_Lite_B601_assembly_coordinates.stl
cad/oak_d_lite/OAK_D_Lite_B601_v2.step
cad/oak_d_lite/revisions/v1/OAK_D_Lite_B601.step
cad/oak_d_lite/source/original_oak1/OAK1_B601_offset_tripod.step
cad/oak_d_lite/revisions/v1/camera_positioned.stl
cad/oak_d_lite/source/DM9095_enclosure.stp
cad/oak_d_lite/OAK_D_Lite_B601_PRINT.stl
cad/oak_d_lite/revisions/v1/OAK_D_Lite_B601_PRINT.stl
cad/grippers/derived/LEFT.stl
cad/grippers/derived/RIGHT_PAD.stl
cad/oak_d_lite/OAK_D_Lite_B601.step
cad/oak_d_lite/OAK_D_Lite_B601_v2_PRINT.stl
cad/oak_d_lite/camera_positioned.stl
cad/printer_bed/LH_deck_four_bolt.stl

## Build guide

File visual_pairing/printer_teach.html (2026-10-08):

# Teach the printer approach

Demonstrate the approach and withdrawal with the jaws unchanged. Gripper control is inactive. Both cameras and the measured arm path are being recorded.

Wrist camera

ArduCam overview

## Camera-guided plate approach · commissioning

The wrist stereo cameras locate the plate’s full well grid independently of bed tag 18. A preview uses the measured plate position and checks bed-attached and fixed printer obstacles separately. Automatic movement is unavailable until scene calibration and physical trials are complete.

Waiting for live plate observations…

Save stereo calibration images Preview approach · no movement

## Plate approach demo

The previous fixed-path demo is disabled while camera-guided targeting is commissioned. It cannot compensate for a moved bed or plate. The preview panel above does not enable robot movement or plate pickup.

The arm is at its demonstrated resting pose; the rail, bed, plate, gantry and syringe are unchanged, and the full 30 cm rail sweep and arm path are clear. Demo · start repeating cycle Pause now Stop after this cycle I have checked the paused arm and the path is still clear. ResumeReturn along completed path

Checking demo readiness…

Keep this window visible while watching the arm. Leaving the window pauses with motor power on. After a complete return, arm motor power turns off automatically.

## Rail · arrow keys

Connecting to rail…

The arm is rested with motor power off, and the rail path is clear. Click here, then hold ← or →Stop rail

Left/right follow the ArduCam view. Hold the arrow to keep moving at a requested 32 mm/s; release to brake to a stop. Leaving this window also stops. Release early before obstacles and either end of the rail. Idle driver disable is configured; release after movement was confirmed by the operator with the replacement shield. Motor current is not measured. Rail position is relative and unhomed.

Connecting — leave both arms at rest.

Align the arms before the first press. Hold to follow: base, shoulder and elbow up to 18°/s; wrist axes up to 24°/s. The first press captures alignment. Keep the leader still while “Taking hold” appears. Release pauses the follower without changing alignment.

Joint limits preserve alignment: if an axis reaches its limit, bring the leader back within range. A new press establishes a new relative reference.

I can support the follower during engagement and watch arm, tool, cable and printer clearance. Press and hold to followPause and hold

Waiting for controller status.

Re-align · use current poses

To resume, match the leader to the held follower using the alignment errors below. If you intentionally repositioned the leader while paused, Re-align accepts the current pair of poses without moving the follower.

Pause keeps motor power on. A controller fault or power loss can remove torque; keep support available. Stop before touching the plate during this approach-only pass.

The follower is physically supported for motor power removal. Remove motor power

Axis | Leader | Follower | Following error | Travel

Direction checks · change only with motors off

Mode Selected axis Reverse selected direction

Use a small movement to check direction before approaching the printer. Model joint limits and the existing local travel limits remain active.

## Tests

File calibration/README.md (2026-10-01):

# Second-arm reference calibration

This procedure records software coordinates without enabling motors, changing
modes, clearing faults, or resetting motor zeros. The active motion configuration
stays blocked. The old first-arm range file is not used.

## First step: record the reference

1. Keep the base fixed. Support the arm, with all motors disabled and other motor
   controllers disconnected. Do not force an enabled joint or push into a stop.
2. Open [Seeed's reference photograph](seeed_reference_pose.jpg). Arrange the arm
   by hand to match the folded geometry: the two long links are horizontal and
   parallel, the upper one folds back over the lower one, and the wrist/gripper
   projects horizontally away from the elbow. Match the wrist housings as well
   as the links. Use a level on the long-link edges; a casual visual match is only
   an initial estimate. Keep the camera mount and cable clear.
3. Mark the base yaw direction on the fixed base/table as the local reference.
   The side photo cannot uniquely establish base yaw or all wrist alignment.
   Photograph the actual arm from the side and above for later geometry review.
   The stock gripper in the photo differs from the installed fingers: don't close
   or force custom fingers to copy it. Joint 7 is excluded from this calibration.
4. While the pose is supported, run:

   ```bash
   uv run calibrate_arm.py reference
   ```

   Type `REFERENCE` when positioned. Ten position samples are taken; more than
   0.5° of movement rejects the capture. Motor status must report disabled.
   The recorder uses fresh position-register queries, rather than treating cached
   feedback as proof of a new position reply.
5. Rest the arm after the capture completes. Review with:

   ```bash
   uv run calibrate_arm.py show
   ```

The saved file is `calibration/arm2_reference.json`; replacements archive the old
file with a timestamp. No current pose is silently treated as reference. The zero
model angles are a candidate based on operator alignment to Seeed's reference;
physical alignment and joint directions remain to be independently checked.

## Direction checks and validation

The guided version now handles direction-only measurements without requiring a
protractor or signed angle input:

```bash
uv run calibrate_arm.py directions
```

It prompts for each of the six joints, always starting at the recorded reference.
It checks the starting angles before asking for a small manual movement in a named
physical direction. It accepts 3–15° of movement on the selected joint and rejects
more than 2° of movement on others. Support the arm throughout. Type `DONE` only if
you performed the described physical direction. Stop if the instruction is unclear
or obstructed. The program sends only read requests; it does not make the movement.

Progress saves after every joint and resumes automatically. To redo one joint:
`uv run calibrate_arm.py directions --joint 3`. This establishes a sign from your
observed direction, **not** an independently measured angular scale or a validation
of the zero/reference pose. The more precise measured-angle method below remains
available. Neither method marks the arm ready for motion.

One reference measurement cannot distinguish a reversed joint direction. For each
joint, return to the reference and move only that joint through an independently
measured signed model angle of 5–20°. Use the URDF axis and right-hand convention,
not the sign shown by the motor. Do not guess the sign from a photo or from whether
an arbitrary movement raised the gripper. Then record, for example:

```bash
uv run calibrate_arm.py direction --joint N --model-delta-deg ANGLE
```

Replace N and ANGLE with the joint and actual measured signed angle. The tool
rejects excessive movement of other joints and mismatched angle magnitudes. These
are measurement commands, not instructions to make a particular physical move.
Have the selected joint's axis/positive direction identified before this step.

The software mapping is `q_model = sign * q_raw + offset`. Signs and offsets stay
unset until measured; recorded travel endpoints cannot supply these quantities.
After all six checks, compare predicted link positions with at least two additional
measured physical poses. This tool intentionally does not certify its own data or
turn on motion. Reference capture alone is not Cartesian calibration.

## Camera and fingertip steps after joint mapping is verified

Keep the 60 mm tag fixed relative to the base. Collect synchronized, stationary
joint and tag observations across at least 15 varied camera poses with rotations
about multiple axes. Solve hand-eye calibration and check a held-out set of poses;
repeated views with nearly identical orientation are insufficient. The existing
`outputs/arm_held.json` and `outputs/tag_pose.json` are not synchronized calibration
pairs. Do not use them as a fitted transform.

Measure/calibrate the actual installed fingertip contact point relative to the
chosen tool frame and retain the corresponding gripper opening. A camera-to-tool
transform alone does not locate the fingertip. Validate at a visible stand-off
before any contact approach. Joint ranges, collision clearance, tracking and
feedback handling must also be checked before executing a new trajectory.

## Sources

Reference photo: https://files.seeedstudio.com/wiki/robotics/projects/lerobot/b601dm_zeroposition.jpg

[Seeed reference-pose instructions](https://wiki.seeedstudio.com/rebot_arm_b601_dm_lerobot/)
show hardware zeroing. Our recorder uses the pose photograph only and **does not**
run those zeroing commands.

[Seeed grasping calibration workflow](https://wiki.seeedstudio.com/rebot_arm_b601_dm_grasping_demo/).
The checked-out DM URDF is at
`vendor/reBotArm_control_py/urdf/DM/urdf/ReBot_Arm_DM.urdf`, commit
`6415d43130d1e143c70dc106096a857ac5556f81`.

## Guided camera-to-wrist collection

All six direction checks have been recorded for this arm. `arm_geometry.py` uses
those software offsets and the pinned DM URDF to calculate the `link6` wrist pose.
The camera capture tool never commands the arm.

1. Fix tag 0 firmly in place and leave the robot base fixed. Its black square is
   configured as 60 mm. Keep the same camera mount and gripper configuration.
2. Run from the project folder:

   ```bash
   uv run calibrate_camera.py capture
   ```

3. Support and move the disabled arm by hand so the whole tag is visible in the
   window. Let it settle; press **Space** to record. Read the message in the window:
   unsuccessful captures explain what to change.
4. Collect **at least 20 different poses**. Keep the tag visible while varying both
   viewing position and wrist orientation: include tilted views in more than one
   direction, not just a left/right sweep. Only use clear, comfortable poses.
   The tag and base must stay fixed across every capture, including resumed runs.
5. Press **Q** to finish, gently rest the arm, then run:

   ```bash
   uv run calibrate_camera.py solve
   ```

Samples save immediately to `calibration/arm2_handeye_samples.json`, with annotated
images. Rerunning capture resumes; if the tag/base moved between sessions, archive
that sample file first and start a new set. A changed joint reference, model, or
tag definition is rejected automatically using a stored fingerprint.

The solver uses OpenCV's Park hand-eye method and holds out every fifth pose for
validation. It rejects inadequate rotation diversity. The candidate's held-out
maximum errors must be no more than 5 mm and 2 degrees. These are consistency
checks, not proof of collision clearance, correct physical zero alignment, or
contact accuracy. Results are saved to `calibration/arm2_handeye_candidate.json`;
`motion_ready` stays false even if validation passes. The actual fingertip contact
point is still a separate measurement. There is no automatic motor enable or
approach in these tools.

[OpenCV hand-eye transform conventions](https://docs.opencv.org/4.12.0/d9/d0c/group__calib3d.html)
use base-from-wrist and camera-from-tag observations to estimate wrist-from-camera.

### First 10-view diagnostic

The first dataset has useful rotational diversity, but its camera/arm relative
rotations disagree by up to 8.29 degrees. Multiple hand-eye solvers show inconsistent
fixed-tag poses. This cannot be repaired simply by changing the camera-to-wrist
translation. Saved photos show curling paper near the tag; a non-flat tag is a
possible contributor, not a proven sole cause. Physical reference alignment and
camera pose estimation remain possible sources.

Mount the tag flat on a rigid board, secure the board, and check that the printed
black square measures 60 mm on both sides. Avoid glare and views nearly edge-on.
If the tag/base placement changes, start a new session:

```bash
uv run calibrate_camera.py capture --new-session
```

This archives the previous JSON without deleting its images. New sessions use
unique image filenames and save unannotated images, corner coordinates, calibration
metadata and frame timestamps for diagnosis. Existing captures remain available;
do not combine observations taken before and after repositioning the board.

### Flat-tag dataset review

The replacement session contains 20 views. The Park fit's four held-out position
errors are 6.46, 1.67, 7.64, and 8.73 mm; orientation errors are 1.08, 2.85, 1.12,
and 0.83 degrees. This is a substantial improvement, but validation still fails
at the original 5 mm / 2 degree thresholds. Candidate files are not activated.

`uv run refine_handeye.py` performs an offline training-only corner reprojection
fit and writes a separate candidate. It does not change the reference, capture
set, camera configuration, or motor settings. The current refinement also fails
validation; it is diagnostic, not an approved replacement. Synthetic tests verify
transform recovery and that held-out corners do not influence fitting. Physical
reference alignment and installed fingertip geometry still need checking; further
captures alone are not currently the prescribed next step.

### External photographs and custom tool geometry

The supplied side/overhead images are recorded in
`calibration/tool_geometry_candidate.json`. The folded pose broadly matches the
reference, but perspective does not establish precision angular alignment. The
installed elongated fingers differ from the stock URDF geometry. Matching-looking
CAD was found in the earlier design workspace: `B601_long_braced45` and
`B601_clean_braced45` share the same contact geometry. Part identity is awaiting
confirmation. Nominal pad points were derived directly from the CAD generator and
are stored in **finger CAD coordinates only**. They must not be used as link6 or
camera-frame targets. Mount registration, actual pad dimensions, gripper opening,
and physical contact-point verification remain outstanding. No motion is enabled.

### Operator-taught contact attempt

`record_contact.py` captured five bracketed joint/image observations in
`calibration/contact_20260930T002532864375Z/`. Contact was reported by the operator;
there is no force-sensor confirmation. The tag is clipped by the image top edge
and blurred in the contact view, so none of the five frames decoded. The raw joint
endpoint is preserved, but this is not a valid visual-servo contact target and
no approach or replay path has been validated. `motion_ready` remains false.

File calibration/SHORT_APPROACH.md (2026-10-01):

# Short taught approach

This is a supervised local replay for the second arm, not a completed autonomous
AprilTag search or visual-servo controller. It uses the operator-taught contact
endpoint because the tag leaves view there. No camera or hand-eye calibration is
silently marked valid. No first-arm limits are used. Motor zeros are never changed.

## Teach a retreat (read-only)

```bash
uv run teach_approach.py teach
```

Keep the tag, base, camera mounting, gripper opening and motor zeros unchanged
throughout this recording and its replay. Support the disabled arm and gently
place a padded fingertip at the desired contact point. This captures a **fresh
contact endpoint and jaw opening**. It no longer requires reproducing the previous
contact angles. Hold steady for capture and wait for `RECORDING` before withdrawing.

For one continuous teaching/replay session, use:

```bash
uv run teach_approach.py teach-replay
```

After saving, keep the arm supported at the retreat endpoint. The script prints a
path preview and proceeds to the attended replay prompts, avoiding a later manual
return to those exact angles. Motors stay disabled until the REPLAY prompt is
accepted; the startup pose checks and all other motion checks still apply.

Follow the terminal prompts. When recording starts, slowly withdraw only a few
centimeters along a clear route, away from the tag. Avoid joint stops and reverse
bends; keep all links, fingers and cables clear. Press Enter to finish while holding
the retreat endpoint steady. This captures the intermediate raw motor angles,
not just the endpoints. Progress is saved only after a valid complete recording.
It rejects abrupt sample jumps above 1 degree, excursions above 10 degrees from
contact, movements too small to distinguish, and a changed gripper opening.

The capture must be done in an attended terminal. It sends only motor read queries.
For `teach`, gently rest the arm after saving. For `teach-replay`, keep it supported at the retreat endpoint until instructed. The file is `calibration/arm2_short_approach.json`;
old completed paths are archived before replacement. Ctrl+C abandons the current
recording without changing torque state.

## Preview and supervised replay

```bash
uv run teach_approach.py preview
uv run teach_approach.py replay
```

Preview does not access hardware. Replay requires manually placing the supported
arm at the taught **retreat endpoint** within 0.5 degrees per joint. It does not
move there from rest. Ensure the entire recorded route and contact target remain
unchanged. The terminal displays the concrete path and starting-pose requirements.
Type REPLAY only after reviewing them. Mode setup and enabling take place with
the arm supported; existing motor gains are not rewritten. No gripper control
commands are sent.

After enabling, the arm holds the retreat endpoint. Move supporting hands clear
and type GO. It follows the recorded retreat in reverse, capped at 0.01 rad/s,
using smooth interpolation between samples. At 80% of the recorded joint-space
arc it holds and asks for TOUCH or BACK. **This pause is not a measured physical
clearance**, and recorded joint-space interpolation is not a collision guarantee.
If there is unexpected contact, use the stop immediately, not the final prompt.

TOUCH permits the remaining taught segment at 0.005 rad/s. The arm immediately
retraces the path to the retreat endpoint after reaching the taught contact angles;
there is no additional forward travel or dwell. Reaching those angles does not
prove contact or control force. BACK (or another response at that pause) retreats
along only the portion already traversed. At the final retreat hold, support the
arm and type SUPPORT to disable and exit.

Ctrl+C, SIGTERM, a fault, a detected control-loop stall or a tracking error attempts
to disable all six arm motors. **Torque-off can let the arm fall.** Keep the hardware
cutoff accessible. Software cannot guarantee a stop after lost communication.
There is no force sensor or force limit in this demo, and no unattended operation.
Do not use it for a rigid collision, an unstable target, or a payload.

## Validation status

Offline tests cover path bounds, bad samples, start mismatch, command-envelope
rejection, partial-enable cleanup and read-only cleanup. Physical teaching/replay
has not yet been performed. The previously recorded single contact endpoint alone
does not define a safe approach path.

New version-2 path files contain their own contact endpoint; older contact captures
are preserved. Tests exercise fresh-contact teaching without any previous contact
file and reject disagreement between the embedded contact and path endpoint.

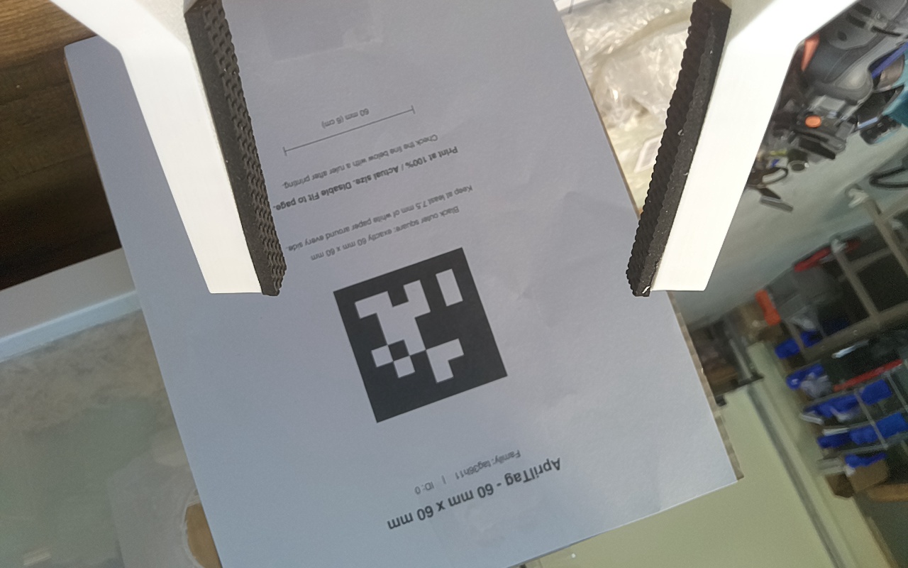
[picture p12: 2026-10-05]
calibration/handeye_20261001T234501896017Z_008_raw.jpg

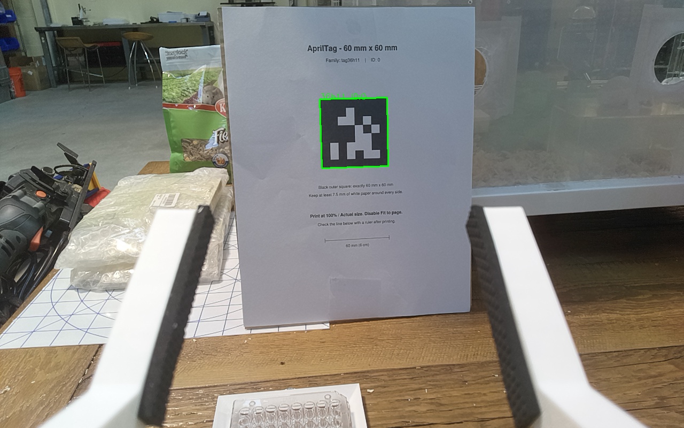
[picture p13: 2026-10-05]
calibration/handeye_20261001T234501896017Z_001.jpg

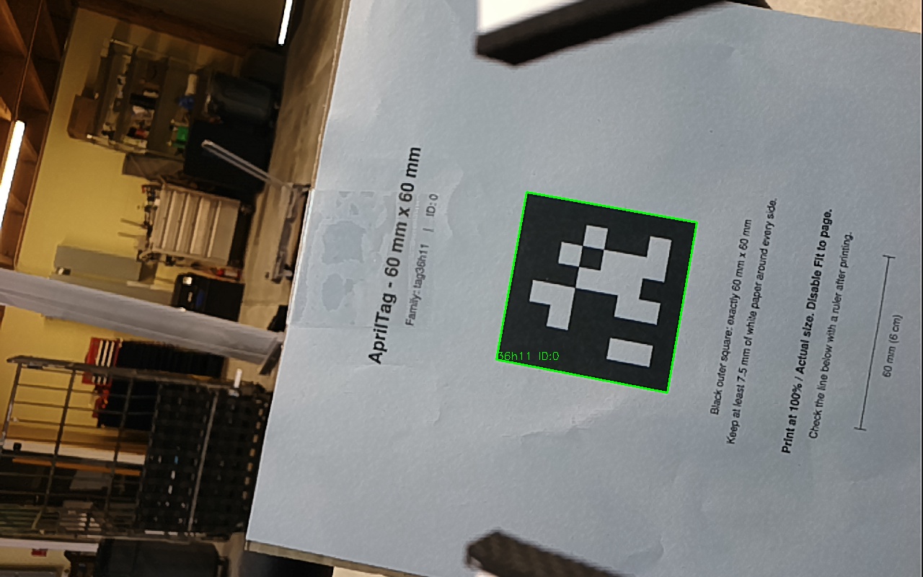
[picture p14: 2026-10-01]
calibration/handeye_20260930T001217703890Z_015.jpg

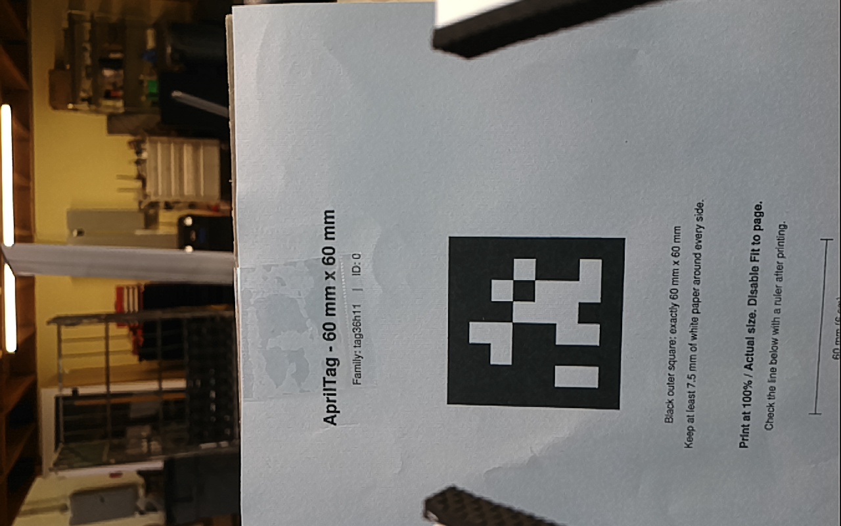
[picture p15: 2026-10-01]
calibration/handeye_20260930T001217703890Z_003_raw.jpg

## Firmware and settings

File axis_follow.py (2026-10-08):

#!/usr/bin/env python3
"""Selected-axis or coordinated REbot following while the operator holds a button."""
import argparse
from datetime import datetime, timezone
import json
import math
from pathlib import Path
import secrets
import signal
import threading
import time
from http.server import ThreadingHTTPServer

from camera_check import CameraCheck
from arm_control import B601_GAINS, GAIN_REGISTERS
from calibrate_arm import Reader
from leader_read import LeaderReader, NAMES
from pairing_dashboard import ASSETS
from wrist_follow import (FollowArm, WristWorkbench, WristTrajectory, HoldGate, handler,
                          MOTOR_TIMEOUT_MS, DM_TIMEOUT_TICKS_PER_MS)

# First three axes use the existing B601 position/velocity gain profile.
# Wrist bend/yaw retain their current position gains. Roll keeps its tested MIT gains.
PROFILES = [
    dict(range=60., speed=18., acceleration=60., measured_speed=60., mode=2),
    dict(range=60., speed=18., acceleration=60., measured_speed=60., mode=2),
    dict(range=90., speed=18., acceleration=60., measured_speed=60., mode=2),
    dict(range=45., speed=24., acceleration=80., measured_speed=75., mode=2),
    dict(range=45., speed=24., acceleration=80., measured_speed=75., mode=2),
    dict(range=45., speed=24., acceleration=80., measured_speed=75., mode=1),
]
TRACKING_ERROR = 8.0
ROLL_MIT_GAINS = (18., 2.)
DEMO_ROLL_MIT_GAINS = (30., 2.6)


class AxisGate(HoldGate):
    """Keep the cause of cancellation, including server-side heartbeat expiry."""
    def __init__(self):
        super().__init__()
        self.reason = 'not_started'

    def cancel(self, reason):
        self.lease = None
        self.reason = reason

    def valid(self, now):
        had_lease = self.lease is not None
        valid = super().valid(now)
        if had_lease and not valid:
            self.reason = 'heartbeat_expired'
        return valid

    def action(self, request, now):
        client, seq = request.get('client'), request.get('seq')
        accepted = isinstance(client, str) and isinstance(seq, int) and seq > self.sequences.get(client, -1)
        super().action(request, now)
        if accepted and request.get('action') == 'release':
            reason = request.get('reason', 'operator_release')
            self.reason = reason[:100] if isinstance(reason, str) else 'operator_release'


class ClutchedTarget:
    """Discard leader travel beyond a limit so reversing responds immediately."""
    def __init__(self, position, leader, sign, low, high):
        self.position, self.leader, self.sign = position, leader, sign
        self.low, self.high = low, high
        self.limited = False

    def update(self, leader):
        if not math.isfinite(leader):
            raise RuntimeError('Invalid leader position')
        desired = self.position + self.sign * (leader-self.leader)
        self.leader = leader
        self.position = max(self.low, min(self.high, desired))
        self.limited = desired <= self.low or desired >= self.high
        return self.position

    def rebase_leader(self, leader):
        if not math.isfinite(leader):
            raise RuntimeError('Invalid leader position')
        self.leader = leader


class ReferencedTarget:
    """Clamp output without changing the reference when leader travel saturates.

    Returning the leader to its press-time reference returns the requested
    follower pose, even after excursions beyond either follower limit.
    """
    def __init__(self, position, leader, sign, low, high):
        if (not all(math.isfinite(v) for v in (position, leader, low, high)) or
                sign not in (-1, 1) or not low <= position <= high):
            raise ValueError('Invalid relative reference')
        self.origin = self.position = position
        self.leader_reference = leader
        self.sign, self.low, self.high = sign, low, high
        self.limited = False

    def rebase_leader(self, leader):
        if not math.isfinite(leader):
            raise RuntimeError('Invalid leader position')
        self.leader_reference = leader
        self.origin = self.position

    def update(self, leader):
        if not math.isfinite(leader):
            raise RuntimeError('Invalid leader position')
        desired = self.origin + self.sign*(leader-self.leader_reference)
        self.position = max(self.low, min(self.high, desired))
        self.limited = desired <= self.low or desired >= self.high
        return self.position


def axis_bounds(geometry, selected, position):
    """Intersect local travel with model limits; permit only inward travel if
    a <=1° software-reference discrepancy places the starting pose just outside.
    No command goes farther outside than the existing supported position.
    """
    limit = geometry.joints[selected].find('limit')
    sign, offset = geometry.signs[selected], math.degrees(geometry.offsets[selected])
    model_low, model_high = [math.degrees(float(limit.get(k))) for k in ('lower','upper')]
    raw_low, raw_high = sorted(((model_low-offset)/sign, (model_high-offset)/sign))
    if not math.isfinite(position) or not raw_low-1 <= position <= raw_high+1:
        raise ValueError(f'{NAMES[selected]} starting pose is outside its model limits; check the supported pose')
    radius = PROFILES[selected]['range']
    return max(position-radius, min(position, raw_low+.25)), min(position+radius, max(position, raw_high-.25))


def raw_signs(saved, geometry):
    signs = []
    for i in range(6):
        check = saved.get('direction_checks', {}).get(str(i+1), {})
        if check.get('sign') not in (-1,1) or check['sign'] != saved['signs'][i]:
            raise ValueError(f'Missing visual direction for joint {i+1}')
        physical = saved.get('relative_follow_checks', {}).get(str(i+1))
        sign = int(check['sign']*geometry.signs[i]) if physical is None else physical.get('raw_leader_to_raw_follower_sign')
        if type(sign) is not int or sign not in (-1,1):
            raise ValueError('Invalid saved relative direction')
        signs.append(sign)
    return signs


def starting_targets(q,limits):
    """Tolerate <=0.1° of idle encoder/settling variation without expanding
    any target boundary. The enable/hold targets remain clipped inside limits.
    """
    targets={}
    for i,(low,high) in limits.items():
        if not math.isfinite(q[i]) or q[i]<low-.1 or q[i]>high+.1:
            raise RuntimeError(f'{NAMES[i]} outside starting envelope: {q[i]:.3f} degrees; allowed {low:.3f} to {high:.3f}. Refresh the supported starting pose.')
        targets[i]=max(low,min(high,q[i]))
    return targets


class AxisArm(FollowArm):
    def __init__(self):
        super().__init__()
        from fast_feedback import configure_library
        self.use_fresh_feedback=configure_library()
        self._fresh_reader=None
        self.selected = 4
        self.original = {}
        self.enabled_indices = set()
        self.demo_roll_stiffness = False
        self.speed_limits = {i:p['measured_speed'] for i,p in enumerate(PROFILES)}
        self.measured_speed_limit = PROFILES[self.selected]['measured_speed']

    def __enter__(self):
        super().__enter__()
        try:
            if self.use_fresh_feedback:
                from fast_feedback import FreshMotorReader
                self._fresh_reader=FreshMotorReader(self.motors)
            return self
        except BaseException:
            Reader.__exit__(self,None,None,None)
            raise

    def select(self, selected):
        if self.active or selected not in range(6):
            raise ValueError('Release and disable before selecting a joint')
        self.selected = selected
        self.measured_speed_limit = PROFILES[selected]['measured_speed']

    def prepare(self):
        if self.active:
            raise RuntimeError('Cannot configure an enabled joint')
        self.read()
        i, m = self.selected, self.motors[self.selected]
        if i not in self.original:
            old = {'mode':m.get_register_u32(10,200), 'timeout':m.get_register_u32(9,200)}
            if old['mode'] not in (1,2,3,4):
                raise RuntimeError('Invalid original motor mode')
            if i < 5:
                gains = [m.get_register_f32(rid,200) for rid in GAIN_REGISTERS]
                if not all(math.isfinite(x) and x>=0 for x in gains) or gains[0]<=0 or gains[2]<=0:
                    raise RuntimeError('Invalid or zero position-controller gains')
                if i < 3:
                    old['gains'] = gains
            self.original[i] = old  # preserve before any writes
        if i < 3:
            for rid,value in zip(GAIN_REGISTERS,B601_GAINS[i]):
                m.write_register_f32(rid,value)
                if not math.isclose(m.get_register_f32(rid,200),value,rel_tol=1e-5,abs_tol=1e-7):
                    raise RuntimeError(f'Joint {i+1} gain readback mismatch')
        m.ensure_mode(PROFILES[i]['mode'],1000)
        if m.get_register_u32(10,200) != PROFILES[i]['mode']:
            raise RuntimeError('Control-mode readback mismatch')
        m.set_can_timeout_ms(MOTOR_TIMEOUT_MS)
        actual = m.get_register_u32(9,200)
        if actual != MOTOR_TIMEOUT_MS*DM_TIMEOUT_TICKS_PER_MS:
            raise RuntimeError(f'Timeout readback mismatch: {actual} ticks')

    def enable(self, position):
        self.enable_group({self.selected:position})

    def prepare_group(self,indices):
        selected = self.selected
        try:
            for i in indices:
                self.select(i)
                self.prepare()
        finally:
            self.select(selected)

    def enable_group(self,targets):
        self.command_group(targets,take_up=True)
        self.active = True
        for i,position in targets.items():
            self.enabled_indices.add(i)  # cleanup also covers partial enable
            self.motors[i].enable()
            self.command_axis(i,position,take_up=True)

    def command_group(self,targets,take_up=False):
        for i,position in targets.items():
            self.command_axis(i,position,take_up=take_up)

    def command(self, position, take_up=False):
        self.command_axis(self.selected,position,take_up)

    def set_demo_roll_stiffness(self,enabled):
        # Transient MIT command gains only; never write EEPROM or change mode.
        # A loaded roll retained ~.95 degrees error at Kp=18. Kp=30 reduces
        # that expected static deflection; Kd scales by sqrt(30/18).
        if type(enabled) is not bool:
            raise ValueError('Invalid demo roll profile')
        if self.active or self.enabled_indices:
            raise RuntimeError('Roll gains can change only with all motors disabled')
        self.demo_roll_stiffness=enabled

    def command_axis(self,i,position,take_up=False):
        if i not in range(6) or not math.isfinite(position):
            raise ValueError('Invalid arm target')
        m = self.motors[i]
        if i == 5:
            kp,kd=DEMO_ROLL_MIT_GAINS if self.demo_roll_stiffness else ROLL_MIT_GAINS
            m.send_mit(math.radians(position),0.,kp,kd,0.)
        else:
            speed=getattr(self,'command_speed_limits',{}).get(i,PROFILES[i]['speed']*1.5)
            if not math.isfinite(speed) or not 0<speed<=60.:
                raise ValueError('Invalid transient command speed limit')
            m.send_pos_vel(math.radians(position), .01 if take_up else math.radians(speed))

    def disable(self):
        errors=[]
        for i in sorted(self.enabled_indices):
            try:
                self.motors[i].disable()
                self.enabled_indices.remove(i)
            except Exception as error:
                errors.append(f'Joint {i+1}: {error}')
        self.active = bool(self.enabled_indices)
        if errors:
            raise RuntimeError('Disable failed; use physical power cutoff. '+'; '.join(errors))

    def __exit__(self,*args):
        try:
            self.disable()
            if self.original:
                self.read()
                for i,old in self.original.items():
                    m = self.motors[i]
                    m.ensure_mode(old['mode'],1000)
                    if m.get_register_u32(10,200) != old['mode']:
                        raise RuntimeError(f'Joint {i+1} mode restoration failed')
                    for rid,value in zip(GAIN_REGISTERS,old.get('gains',[])):
                        m.write_register_f32(rid,value)
                        if not math.isclose(m.get_register_f32(rid,200),value,rel_tol=1e-5,abs_tol=1e-7):
                            raise RuntimeError(f'Joint {i+1} gain restoration failed')
                    m.write_register_u32(9,old['timeout'])
                    if m.get_register_u32(9,200) != old['timeout']:
                        raise RuntimeError(f'Joint {i+1} timeout restoration failed')
        finally:
            if self._fresh_reader:self._fresh_reader.close();self._fresh_reader=None
            Reader.__exit__(self,*args)


class AxisWorkbench(WristWorkbench):
    target_mapper = ClutchedTarget
    response_time = .08
    brake_at_target = False

    def make_target_mappers(self, baseline, leader, following, limits):
        return {j:self.target_mapper(baseline[j], leader[j], self.follow_signs[j], *limits[j])
                for j in following}

    def update_take_up_reference(self, mapped, leader, following):
        for j in following:
            mapped[j].rebase_leader(leader[j])

    def __init__(self,pairing):
        super().__init__(pairing)
        self.pairing = Path(pairing)
        self.saved = json.loads(self.pairing.read_text())
        self.follow_signs = raw_signs(self.saved,self.geometry)
        self.selected = 4  # next hinge inward from the successful roll test
        self.control_mode = 'follow_all'
        self.axis_trials = []
        self.revision = 0
        self.bounds = None
        self.observed = set()
        self.gate = AxisGate()
        self.powered = False
        self.feedback_reader = None
        self.disable_requested = False
        self.pause_reason = None
        self.camera_check = CameraCheck(self.geometry)
        self.joint_calibration = None
        self.log_path = Path('outputs')/f'axis_follow_{self.session}.jsonl'

    def publish(self, name, **values):
        super().publish(name, **values)
        if name == 'follower' and hasattr(self, 'camera_check'):
            self.camera_check.add_joints(time.monotonic(), values['angles'], powered=self.powered,
                following=self.active_id is not None or self.gate.lease is not None,
                all_powered=self.control_mode == 'follow_all', fault=self.fault)

    def fresh_leader(self):
        source = self.sources.get('leader',{})
        if 'angles' not in source or time.monotonic()-source['time'] > .25:
            raise RuntimeError('Leader disconnected or stale')
        return source['angles'][self.selected]

    def save_direction(self,confirmed):
        checks = self.saved.setdefault('relative_follow_checks',{})
        key = str(self.selected+1)
        old = checks.get(key,{})
        updated = {**old, 'raw_leader_to_raw_follower_sign':self.follow_signs[self.selected],
                   'corrected_direction_physically_confirmed':confirmed,
                   'method':'operator_confirmed_physical_following' if confirmed else 'operator_reversed_direction_in_dashboard',
                   'updated_utc':datetime.now(timezone.utc).isoformat(), 'source_log':str(self.log_path)}
        if old:
            self.saved.setdefault('relative_follow_history',[]).append({'joint':self.selected+1,**old})
        checks[key] = updated
        temp = self.pairing.with_suffix('.tmp')
        temp.write_text(json.dumps(self.saved,indent=2,allow_nan=False)+'\n')
        temp.replace(self.pairing)

    def action(self,request):
        if request.get('action') == 'camera_capture':
            self.camera_check.arm_capture()
            return
        if request.get('action') == 'camera_restart':
            self.camera_check.restart()
            return
        with self.lock:
            op = request.get('action')
            if op in ('select','reverse','confirm_direction','set_control_mode'):
                if self.powered or self.active_id is not None or self.gate.lease is not None:
                    raise ValueError('Support the arm and remove motor power before changing configuration')
                if self.fault:
                    raise ValueError('Restart the server after this fault')
                if request.get('revision') != self.revision:
                    raise ValueError('The selected joint changed; refresh status')
                if op == 'set_control_mode':
                    mode=request.get('control_mode')
                    if mode not in ('single','hold_all','follow_all'):
                        raise ValueError('Unknown following mode')
                    self.control_mode=mode
                    self.bounds=None
                elif op == 'select':
                    joint = request.get('joint')
                    if type(joint) is not int or joint not in range(1,7):
                        raise ValueError('Select joint 1 through 6')
                    self.selected = joint-1
                    self.bounds = None
                elif op == 'reverse':
                    self.follow_signs[self.selected] *= -1
                    self.observed.discard(self.selected)
                    self.save_direction(False)
                else:
                    if self.selected not in self.observed:
                        raise ValueError('First move this axis using a hold, then confirm the physical direction')
                    self.save_direction(True)
                self.revision += 1
                self.ready = False
                return
            if op == 'disable':
                if request.get('support_confirmed') is not True:
                    raise ValueError('Support the arm before removing motor power')
                release = {**request, 'action':'release', 'reason':'operator_torque_off'}
                client, seq = request.get('client'), request.get('seq')
                previous_seq = self.gate.sequences.get(client, -1) if isinstance(client, str) else -1
                self.gate.action(release, time.monotonic())
                if seq > previous_seq:
                    self.disable_requested = True
                    self.ready = False
                    self.record('torque_off_requested', reason='operator_torque_off')
                return
            if op == 'press' and self.disable_requested:
                raise ValueError('Wait for motor power removal to finish')
            if op == 'release':
                before = self.gate.lease
                super().action(request)
                if before is not None and self.gate.lease is None:
                    self.record('pause_requested', reason=self.gate.reason)
                return
            if op == 'press' and (request.get('joint') != self.selected+1 or request.get('revision') != self.revision):
                raise ValueError('Joint selection changed; try the hold again')
            super().action(request)

    def snapshot(self):
        camera_status = self.camera_check.snapshot()
        with self.lock:
            result = super().snapshot()
            result['camera_check'] = camera_status
            result['joint_calibration'] = self.joint_calibration
            cfg = PROFILES[self.selected]
            result.update(selected_joint=self.selected+1, selected_name=NAMES[self.selected], revision=self.revision,
                feedback_reader=self.feedback_reader,
                control_mode=self.control_mode, axis_trials=self.axis_trials,
                active=self.powered, powered=self.powered, following=self.active_id is not None,
                pause_reason=self.pause_reason, tracking_error_limit_deg=TRACKING_ERROR,
                power_state='unknown_after_fault' if self.fault else ('on' if self.powered else 'off'),
                speed_limit_deg_s=cfg['speed'], travel_limit_deg=cfg['range'], acceleration_limit_deg_s2=cfg['acceleration'],
                bounds=self.bounds, directions=[bool(self.saved.get('relative_follow_checks',{}).get(str(i+1),{}).get('corrected_direction_physically_confirmed')) for i in range(6)],
                follow_sign=self.follow_signs[self.selected], can_confirm=self.selected in self.observed)
            return result
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

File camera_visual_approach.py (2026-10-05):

#!/usr/bin/env python3
"""Camera-checked noncontact approach using current AxisArm control; preview default."""
import argparse,json,math,threading,time,subprocess
from datetime import datetime,timezone
from pathlib import Path
import numpy as np
from axis_follow import AxisArm,axis_bounds
from arm_geometry import Geometry
from pairing_dashboard import Workbench
from camera_check import CameraCheck
from calibrate_joint_motion import Runner
from rise_approach import Planner


def route(start,forward_m=.06,bend_view=0.):
    if forward_m not in (.06,.12,.20,.30) or bend_view not in (0.,6.):raise ValueError('Unsupported bounded route')
    p=Planner(np.radians(start));poses=[list(start)]
    view=list(start);view[4]+=6.;view[3]+=bend_view;poses.append(view)
    p.start=np.radians(view);p.base=p.g.transform(p.start)
    existing={i:axis_bounds(p.g,i,start[i]) for i in range(6)}
    if forward_m>.06:
        radii=[20.,140.,140.,90.,30.,20.]
        for i in range(6):
            limit=p.g.joints[i].find('limit');sign=p.g.signs[i];offset=math.degrees(p.g.offsets[i])
            a,b=sorted((math.degrees(float(limit.get(k)))-offset)/sign for k in ('lower','upper'))
            existing[i]=(max(start[i]-radii[i],min(start[i],a+1.)),min(start[i]+radii[i],max(start[i],b-1.)))
    p.low=np.radians([existing[i][0] for i in range(6)]);p.high=np.radians([existing[i][1] for i in range(6)])
    for h in np.arange(.005,.051,.005):poses.append(np.degrees(p.lift(float(h))).tolist())
    q=np.radians(poses[-1])
    for _ in range(round(forward_m/.005)):
        q=p.forward(q,.005)
        # This position approach does not need roll changes. Preserve the
        # measured starting roll rather than chasing small IK roll adjustments.
        q[5]=p.start[5]
        poses.append(np.degrees(q).tolist())
    g=p.g;limits=existing
    for point in poses:
        if any(not limits[i][0]<=point[i]<=limits[i][1] for i in range(6)):
            raise ValueError('Route leaves existing raw joint limits')
    return poses,limits


def fast_indices(poses, max_error=.20):
    """Merge verified waypoints only where joint-space chord error is bounded."""
    qs=np.asarray(poses);result=[0]
    # Preserve viewing offset, gentle initial lift and the lift/forward corner.
    for end in sorted(set([1,3,11,len(qs)-1])):
        if end>=len(qs):continue
        while result[-1]<end:
            start=result[-1];chosen=start+1
            for candidate in range(start+2,end+1):
                u=np.linspace(0,1,candidate-start+1)[:,None]
                chord=qs[start]+u*(qs[candidate]-qs[start])
                if np.max(abs(chord-qs[start:candidate+1]))>max_error:break
                chosen=candidate
            result.append(chosen)
    return result


def movement_duration(delta,speed,acceleration,minimum=.25):
    distance=float(np.max(abs(delta)))
    return max(minimum,1.5*distance/speed,math.sqrt(6*distance/acceleration))


def paced_progress(origin,delta,progress,advance,duration,actual,max_lag):
    """Advance along the same segment, reserving tracking margin at high speed."""
    def target(p):
        u=min(1.,p/duration)
        return origin+delta*(u*u*(3-2*u))
    proposed=min(duration,progress+advance)
    if np.max(abs(target(proposed)-actual))<=max_lag:return proposed
    low,high=progress,proposed
    for _ in range(16):
        middle=(low+high)/2
        if np.max(abs(target(middle)-actual))<=max_lag:low=middle
        else:high=middle
    return low


class RouteRunner(Runner):
    def __init__(self,w,arm,start,limits,output,poses):
        super().__init__(w,arm,start,limits,output)
        qs=np.array(poses);self.low=qs.min(0)-.05;self.high=qs.max(0)+.05
        self.speed=2.25;self.acceleration=9.;self.clearance=.315;self.tracking_limit=2.;self.pacing_lag=1.1
        self.settle_tolerance=np.full(6,.5)
    def tick(self,moving=False,take_up=False):
        q=self.arm.read();now=time.monotonic();dt=now-self.last
        if not 0<dt<.3:raise RuntimeError('Motor loop stalled')
        if max(abs(q[i]-self.targets[i]) for i in range(6))>self.tracking_limit:raise RuntimeError(f'Tracking error exceeds {self.tracking_limit} degrees')
        allowance=np.where(self.high-self.low>.2,self.tracking_limit,.5)
        outside=np.where((np.array(q)<self.low-allowance)|(np.array(q)>self.high+allowance))[0]
        if len(outside):raise RuntimeError(f'Measured joints {(outside+1).tolist()} left route envelope: {q}')
        if any(not self.limits[i][0]-.5<=q[i]<=self.limits[i][1]+.5 for i in range(6)):
            raise RuntimeError('Measured joint left absolute joint bounds')
        self.arm.command_group(self.targets,take_up=take_up)
        self.w.camera_check.add_joints(now,q,powered=True,following=moving,all_powered=True,fault=None)
        self.rows.append({'time':now,'raw_deg':q,'target_deg':list(self.targets.values()),'moving':moving,'cruise_cap_deg_s':self.speed,'motor_torques_nm':[m.get_state().torq for m in self.arm.motors],'motor_temperatures_c':[[m.get_state().t_mos,m.get_state().t_rotor] for m in self.arm.motors]})
        self.last=now;time.sleep(.005);return q
    def vision_ready(self):
        if not super().vision_ready():return False
        with self.w.camera_check.lock:
            T=np.array([f for f in self.w.camera_check.frames if f.get('valid')][-1]['T_camera_tag'])
            return abs(float(T[:3,2]@T[:3,3]))>self.clearance
    def go(self,goal,returning=False):
        if not np.isfinite(goal).all() or np.any(np.array(goal)<self.low) or np.any(np.array(goal)>self.high):raise RuntimeError('Target leaves route')
        origin=np.array(list(self.targets.values()));delta=np.array(goal)-origin
        duration=movement_duration(delta,self.speed,self.acceleration,getattr(self,'minimum_duration',.25))
        began=time.monotonic();previous=began;progress=0.
        while True:
            if not returning and not self.vision_ready():raise ValueError('Camera freshness or tag visibility lost')
            now=time.monotonic();dt=now-previous;previous=now
            if now-began>max(12.,duration*4):raise ValueError('Movement could not keep up with its paced target')
            # Slow the trajectory clock before lag reaches the configured tracking
            # fault. Keep commanding/reading all motors throughout each pause.
            actual=np.array(self.rows[-1]['raw_deg']) if self.rows else origin
            lag=float(np.max(abs(actual-np.array(list(self.targets.values())))))
            advance=min(dt,.06)*max(0.,min(1.,(self.pacing_lag-lag)/.5))
            progress=paced_progress(origin,delta,progress,advance,duration,actual,self.tracking_limit-.5)
            u=min(1.,progress/duration);target=origin+delta*(u*u*(3-2*u))
            self.targets=dict(enumerate(target.tolist()));q=self.tick(moving=True)
            if u>=1:break
        self.settle(goal,returning=returning)
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

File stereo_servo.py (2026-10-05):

"""Incremental stereo position servo. Optional bounded final approach to the estimated paper plane."""
import json,math,time
from pathlib import Path
import cv2
import numpy as np
from arm_geometry import Geometry
from rotation_math import rotation_vector

TIP_B=np.array([-.0028641976884,.0008496377972,.1551784683549])
OTHER_TIP_B=np.array([.0822,.0008,.1527])
TAG_POINT=np.array([0.,-.035,0.])  # white border, leaving the black pattern visible


def mean_pose(rows):
    matrices=np.array([r['T_camera_b_tag'] for r in rows])
    t=matrices[:,:3,3]
    if np.max(t.std(0))>.001:raise ValueError('Stereo position not stationary to 1 mm')
    u,_,v=np.linalg.svd(matrices[:,:3,:3].mean(0));fix=np.eye(3);fix[2,2]=np.linalg.det(u@v)
    R=u@fix@v
    span=max(float(np.linalg.norm(cv2.Rodrigues(R.T@x)[0])) for x in matrices[:,:3,:3])
    if span>math.radians(1.5):raise ValueError('Stereo orientation still changing')
    T=np.eye(4);T[:3,:3]=R;T[:3,3]=t.mean(0)
    return T


def geometry_error(T,standoff=.03):
    normal=T[:3,2];contact=T[:3,:3]@TAG_POINT+T[:3,3]
    delta=contact+normal*standoff-TIP_B
    gap=float(normal@(TIP_B-contact))
    other_gap=float(normal@(OTHER_TIP_B-contact))
    lateral=float(np.linalg.norm((TIP_B-contact)-normal*gap))
    return delta,gap,other_gap,lateral


def step(geometry,q_deg,T,X_b,limits,standoff=.03,travel_m=.002,joint_deg=.5,contact=False):
    """Small nominal-Jacobian step; its actual effect must be measured again."""
    if not .00025<=travel_m<=.020 or not .1<=joint_deg<=4.:raise ValueError('Invalid incremental movement bound')
    if standoff<.03 and not contact:raise ValueError('Contact is not enabled in this controller')
    if standoff<0:raise ValueError('No commanded penetration beyond the estimated paper plane')
    q=np.radians(q_deg);C=geometry.transform(q)@X_b;tip=(C@np.r_[TIP_B,1])[:3]
    delta,gap,other,lateral=geometry_error(T,standoff)
    if not contact and min(gap,other)<.015:raise ValueError('Reached fingertip noncontact clearance guard')
    if contact and (gap<-.001 or other<.002):raise ValueError('Contact clearance guard reached')
    if contact and (travel_m>.002 or joint_deg>.5 or (gap<.010 and travel_m>.0005)):
        raise ValueError('Final contact movement exceeds its small-step bound')
    desired=C[:3,:3]@delta
    desired*=min(1.,travel_m/max(np.linalg.norm(desired),1e-12))
    target_R=C[:3,:3]@T[:3,:3]@np.diag([-1.,1.,-1.])
    rotate=cv2.Rodrigues(C[:3,:3].T@target_R)[0].ravel()
    rotate*=min(1.,math.radians(.25)/max(np.linalg.norm(rotate),1e-12))
    J=np.zeros((6,6));eps=1e-5
    for i in range(5):
        qq=q.copy();qq[i]+=eps;N=geometry.transform(qq)@X_b
        J[:3,i]=100*((N@np.r_[TIP_B,1])[:3]-tip)/eps
        J[3:,i]=rotation_vector(C[:3,:3].T@N[:3,:3])/eps
    if contact or gap<.06:
        J[3:,:]=0.;rotate[:]=0.
    target=np.r_[100*desired,rotate]
    dq=np.linalg.solve(J.T@J+.02**2*np.eye(6),J.T@target)
    dq*=min(1.,math.radians(joint_deg)/max(np.max(abs(dq)),1e-12))
    candidate=np.degrees(q+dq)
    for i,(lo,hi) in limits.items():candidate[i]=np.clip(candidate[i],lo,hi)
    predicted=J@np.radians(candidate-np.array(q_deg))
    if np.linalg.norm(candidate-np.array(q_deg))<.005 or desired@predicted[:3]<=0:
        raise ValueError('No bounded progress toward the stereo target')
    return candidate.tolist(),{'gap_m':gap,'other_finger_gap_m':other,'lateral_error_m':lateral,'error_norm_m':float(np.linalg.norm(delta))}
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

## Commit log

2026-10-05 Add REbot leader control, camera calibration and plate trial tooling
2026-10-08 Add printer teaching, rail demo and faster fresh motor feedback
    [B601_clean_braced45_assembly.step, DM9095_enclosure.STL, LEFT.stl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]
2026-10-08 Recover demo readiness after power cycling at supported rest
2026-10-08 Restore sequential feedback and prioritize motor cleanup on demo faults
2026-10-08 Prevent wrist roll pacing deadlock and report sustained tracking stalls
    [blended_motion.py]
2026-10-08 Tune demo-only roll stiffness for loaded endpoint convergence
    [axis_follow.py]
2026-10-08 Retire plate-contact route and validate elevated standoff demo
2026-10-08 Add stereo plate localization and target-relative planning previews
2026-10-08 Add read-only stereo framing snapshots for calibration
